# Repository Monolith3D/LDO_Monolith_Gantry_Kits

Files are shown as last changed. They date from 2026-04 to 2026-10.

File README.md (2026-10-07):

[][cc-by-nc-sa]

# LDO Monolith Gantry Kits

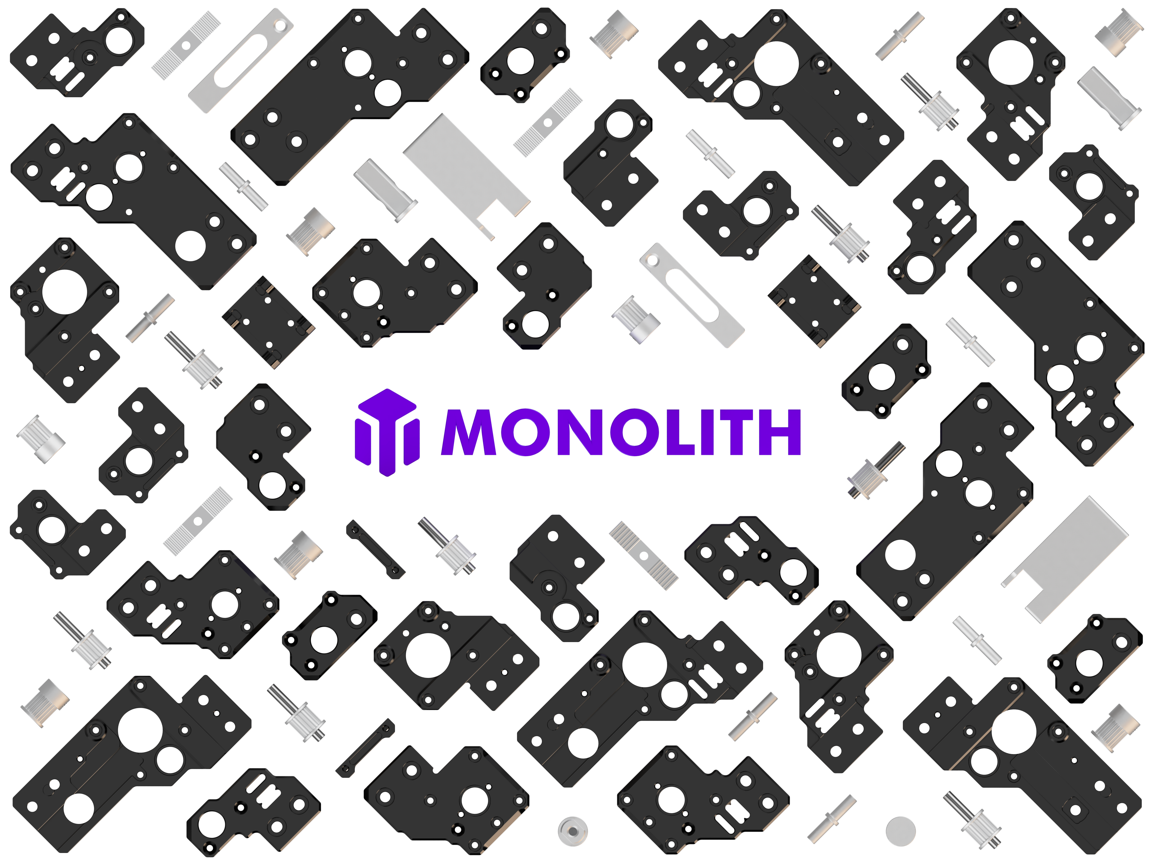
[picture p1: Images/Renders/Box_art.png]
LDO Monolith Gantry Kit box art


Official milled [Monolith Gantry](https://github.com/Monolith3D/Monolith_Gantry) kits and milled Z-joint kits, manufactured by [LDO](https://ldomotion.com/).

## Start Here

<a href="https://build.monolith3d.xyz/">
  <picture>
    <source media="(prefers-color-scheme: dark)" srcset="https://raw.githubusercontent.com/Monolith3D/MISC/main/Common_repo_files/monolith-builder-dark.png">
    <source media="(prefers-color-scheme: light)" srcset="https://raw.githubusercontent.com/Monolith3D/MISC/main/Common_repo_files/monolith-builder-light.png">
    Get started in Monolith Builder
  </picture>
</a>

Monolith Builder guides you through assembly step by step with interactive 3D animations. Legacy PDF assembly manuals remain available during the transition.

- [Legacy PDF assembly manuals](Docs/)
- [Printed parts](STLs/)
- [CAD reference files](CAD/)
- [Batch notes](Docs/batch_notes.md)
- [Photos and renders](Images/)

## Products

### Gantry Kits

[Gantry kit details](Gantry_Kits.md): Milled parts and supporting hardware for 2WD or AWD builds.

**Vendors**

- US: [West3D](https://west3d.com/products/monolith-cnc-gantry-by-ldo-systems-v2-4-and-trident-compatible-with-2wd-and-awd), [Fabreeko](https://www.fabreeko.com/products/monolith-gantry-cnc-kit-by-ldo), [KB-3D](https://kb-3d.com/store/motion/8785-9638-ldo-monolith-awd-9mm-cnc-gantry-kit-r1-multiple-types.html)
- Canada: [3D Lab Tech](https://www.3dlabtech.ca/product/ldo-monolith-cnc-gantry-kit/)
- Australia: [Dremc](https://store.dremc.com.au/products/ldo-monolith-cnc-gantry-kit-v2-4-trident?_pos=2&_sid=165a04a36&_ss=r)
- UK: 123-3D ([V2](https://www.123-3d.co.uk/LDO-Monolith-CNC-Gantry-KIT-Voron-2-4-LDO-MLG-V2-i15158.html), [Trident](https://www.123-3d.co.uk/LDO-Monolith-CNC-Gantry-KIT-Voron-Trident-LDO-MLG-VT-i15159.html)), [onetwo3D](https://www.onetwo3d.co.uk/product/ldo-monolith-cnc-gantry-kit/), [JB3D](https://jb3d.uk/product/cnc-monolith-gantry-by-cloakedwayne/)
- Germany: [3DPartner](https://www.partner-3d.de/3d-druck-ersatzteile/)
- France: [MyRigs](https://myrigs3d.com/products/monolith-cnc-gantry-by-ldo-systems-v2-4-and-trident-compatible-with-2wd-and-awd)
- Hungary: Zen3D Laboratories ([V2](https://shop.zen3d.eu/cnc-monolith-gantry), [Trident](https://shop.zen3d.eu/cnc-monolith-gantry-trident))
- Russia: RRF3D ([V2](https://rrf3dshop.ru/catalog/mekhanika/nabory/nabor-monolith-cnc-gantry-dlya-voron-2-4r2/), [Trident](https://rrf3dshop.ru/catalog/mekhanika/nabory/nabor-monolith-cnc-gantry-4awd-dlya-voron-trident/))
- India: [DConqueror3D](https://dc3d.in/shop/voron-v2-4-parts/ldo-monolith-cnc-gantry-kit/), [Zee3D](https://www.zee3d.in/product-page/monolith-cnc-gantry-kit)
- Sweden: [3D Katten](https://3dkatten.se/products/monolith-cnc-kit-2wd-awd)
- Denmark: 3DO ([V2](https://3do.dk/en/frame-kits/4621-ldo-monolith-cnc-gantry-kit-voron-24-v2.html), [Trident](https://3do.dk/en/frame-kits/4622-ldo-monolith-cnc-gantry-kit-voron-trident-vt.html))
- Norway: [Frem3D](https://frem3d.no/en/products/monolith-cnc-gantry-av-ldo-systems-v2-4-og-trident-med-2wd-og-awd)
- Netherlands: [Levendigs](https://levendigs.com/)
- China: [LDO direct](https://store.ldomotion.com/products/ldo-monolith-cnc-gantry-kit-for-voron-2-4-trident)

### Milled Z-Joint Kit

[Milled Z-joint kit details](Milled_Z_Joints.md): Metal replacements for the hybrid Z-joints in the LDO Monolith V2 Gantry Kit, sold separately.

**Vendors**

- US: [West3D](https://west3d.com/products/monolith-cnc-z-joint-kit-by-ldo-motors)
- France: [MyRigs](https://myrigs3d.com/products/ldo-monolith-cnc-z-joint-kit)
- Hungary: [Zen3D Laboratories](https://shop.zen3d.eu/monolith-cnc-z-joint-kit)

## Support

For kit hardware defects or missing kit hardware, use the LDO or reseller support path.

For Monolith design, configuration, and documentation questions, use the Monolith documentation and community channels.

For third-party toolheads, probes, electronics, or firmware behavior, check the relevant upstream project.

Join the Discord (https://discord.gg/sJQeTYUPuy)
Join the Monolith Discord (https://discord.gg/monolith3d)

[Design, production, and testing acknowledgements](Acknowledgements.md)

<br/><br/><br/><br/>
This work is licensed under a
[Creative Commons Attribution-NonCommercial-ShareAlike 4.0 International License][cc-by-nc-sa].

[][cc-by-nc-sa]

[cc-by-nc-sa]: http://creativecommons.org/licenses/by-nc-sa/4.0/
[cc-by-nc-sa-image]: https://licensebuttons.net/l/by-nc-sa/4.0/88x31.png
[cc-by-nc-sa-shield]: https://img.shields.io/badge/License-CC%20BY--NC--SA%204.0-lightgrey.svg

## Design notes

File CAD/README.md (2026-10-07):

# CAD

This folder contains STEP reference files for kit-specific subassemblies, printed parts, and helper tools.

For a complete gantry assembly as a single STEP file, select your configuration and printer size in [Monolith Builder](https://build.monolith3d.xyz/). The generated assembly is included in the downloadable build package.

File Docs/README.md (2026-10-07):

## Monolith Builder

<a href="https://build.monolith3d.xyz/">
  <picture>
    <source media="(prefers-color-scheme: dark)" srcset="https://raw.githubusercontent.com/Monolith3D/MISC/main/Common_repo_files/monolith-builder-dark.png">
    <source media="(prefers-color-scheme: light)" srcset="https://raw.githubusercontent.com/Monolith3D/MISC/main/Common_repo_files/monolith-builder-light.png">
    Get started in Monolith Builder
  </picture>
</a>

Monolith Builder guides you through assembly step by step with interactive 3D animations. Legacy PDF assembly manuals remain available during the transition.

## Legacy PDF Assembly Manuals

| Printer | Batch 1 | Batch 2+ |
|---|---|---|
| Voron V2 | [V2 Batch 1](LDO_Monolith_Gantry_Kit_Manual_V2_Batch_1.pdf) | [V2 Batch 2+](LDO_Monolith_Gantry_Kit_Manual_V2_Batch_2_Plus.pdf) |
| Voron Trident | [Trident Batch 1](LDO_Monolith_Gantry_Kit_Manual_VT_Batch_1.pdf) | [Trident Batch 2+](LDO_Monolith_Gantry_Kit_Manual_VT_Batch_2_Plus.pdf) |

## Batch Notes

Check the [batch notes](batch_notes.md) before assembly.

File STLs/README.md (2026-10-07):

# STLs

This folder contains the LDO-kit-specific printed parts and helper tools.

## Included Here

- [LDO_V2_FT_spacer.stl](LDO_V2_FT_spacer.stl)
- [LDO_9mm_VT_NP_spacer.stl](LDO_9mm_VT_NP_spacer.stl)
- [LDO_9mm_pulley_alignment_helper.stl](Tools/LDO_9mm_pulley_alignment_helper.stl)
- [Cable_management_clip_L.stl](Cable_management/Cable_management_clip_L.stl)
- [Cable_management_clip_M.stl](Cable_management/Cable_management_clip_M.stl)
- [Cable_management_clip_S.stl](Cable_management/Cable_management_clip_S.stl)

## Shared with Main Monolith Gantry

Some printed files used by this kit are shared with the main Monolith Gantry repo:

- [Hybrid_V2_Z_joint_a.stl](https://github.com/Monolith3D/Monolith_Gantry/blob/main/STLs/Z_joints/Hybrid_Z_joints/Hybrid_V2_Z_joint_a.stl)
- [Hybrid_V2_Z_joint_b.stl](https://github.com/Monolith3D/Monolith_Gantry/blob/main/STLs/Z_joints/Hybrid_Z_joints/Hybrid_V2_Z_joint_b.stl)
- [Printed_Hybrid_V2_Z_joint_spacer_NP.stl](https://github.com/Monolith3D/Monolith_Gantry/blob/main/STLs/Z_joints/Printed_Hybrid_V2_Z_joint_spacer_NP.stl)
- [V2_Z_idler_spacer.stl](https://github.com/Monolith3D/Monolith_Gantry/blob/main/STLs/V2_Z_idler_spacer.stl)
- [X_endstop_housing.stl](https://github.com/Monolith3D/Monolith_Gantry/blob/main/STLs/X_endstop_housing.stl)
- [Y_endstop_housing.stl](https://github.com/Monolith3D/Monolith_Gantry/blob/main/STLs/Y_endstop_housing.stl)

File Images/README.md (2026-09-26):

# Images

## Renders

| Image | Image | Image |
| --- | --- | --- |
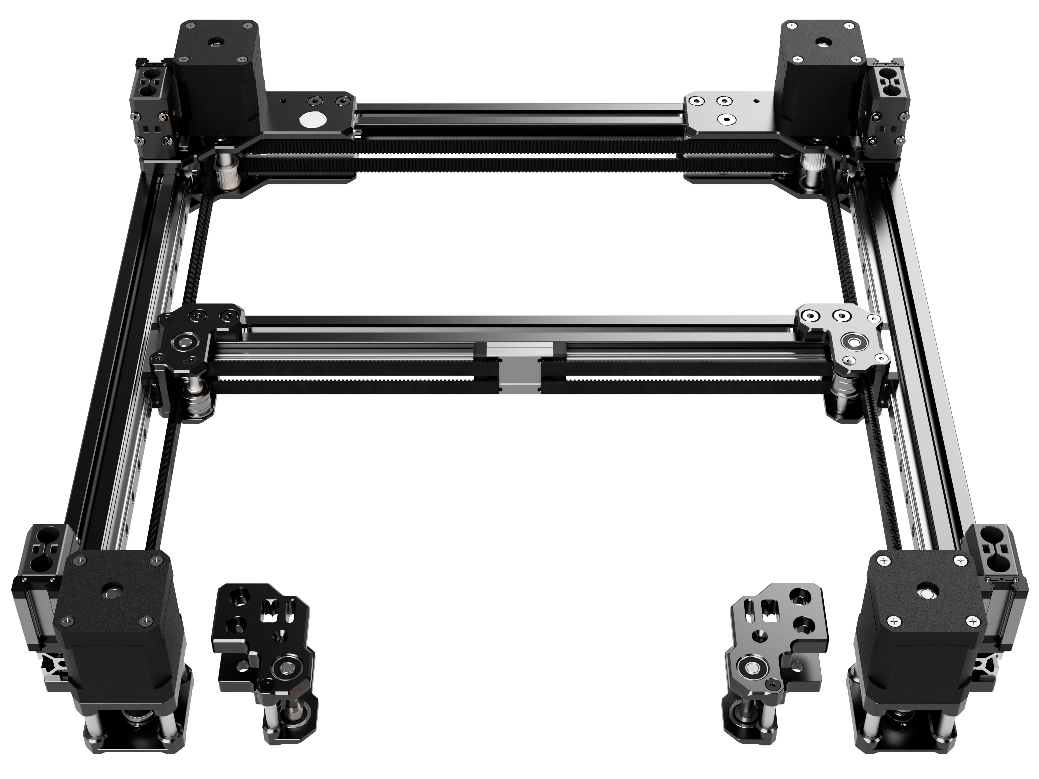
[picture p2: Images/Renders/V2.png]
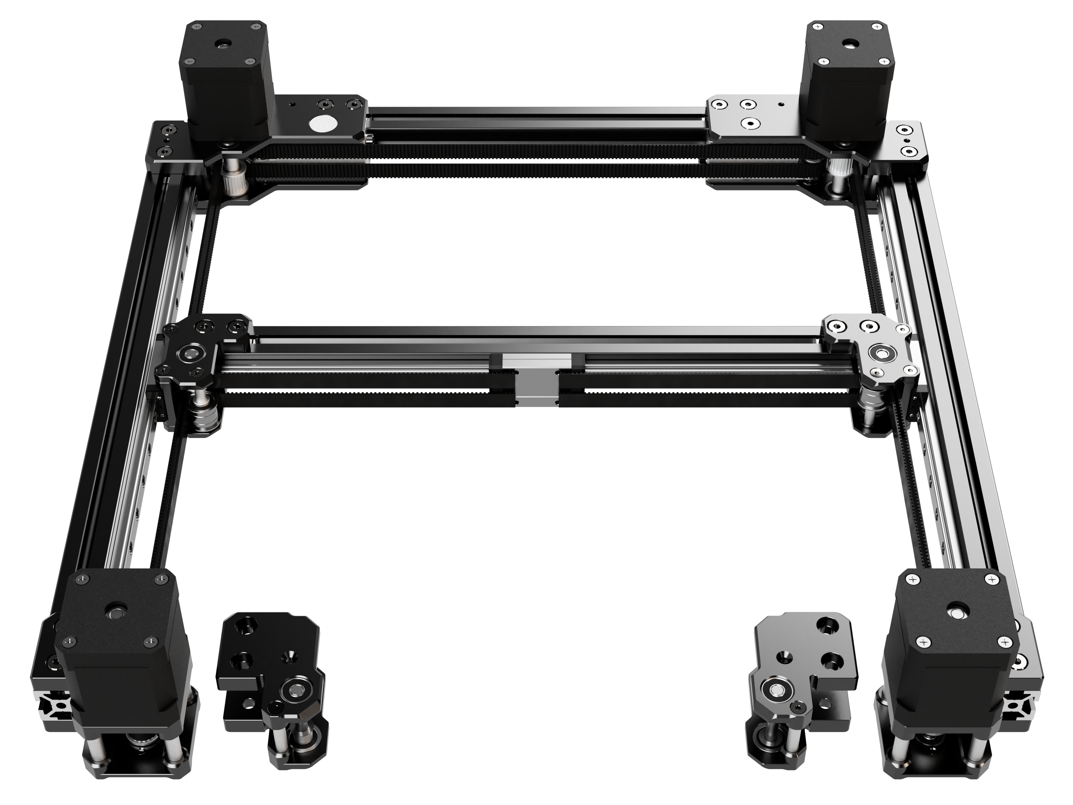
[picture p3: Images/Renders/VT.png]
| [<br>Box art](Renders/Box_art.png) | [<br>V2 kit render](Renders/V2.png) | [<br>VT kit render](Renders/VT.png) |
| [<br>XY-joint](Renders/XY-joint.png) | [<br>Rear mount](Renders/Rear_mount.png) | [<br>Front mount](Renders/Front_mount.png) |

## Milled Z-joint kit

| Image | Image | Image |
| --- | --- | --- |
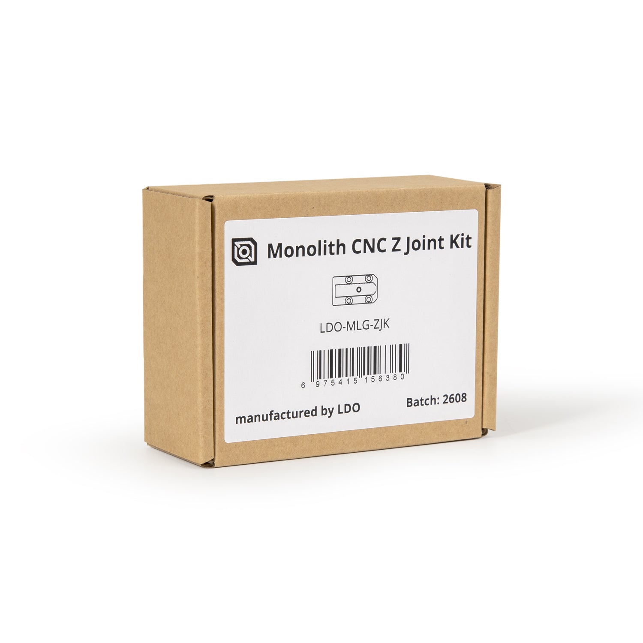
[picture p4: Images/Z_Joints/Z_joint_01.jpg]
Packaging
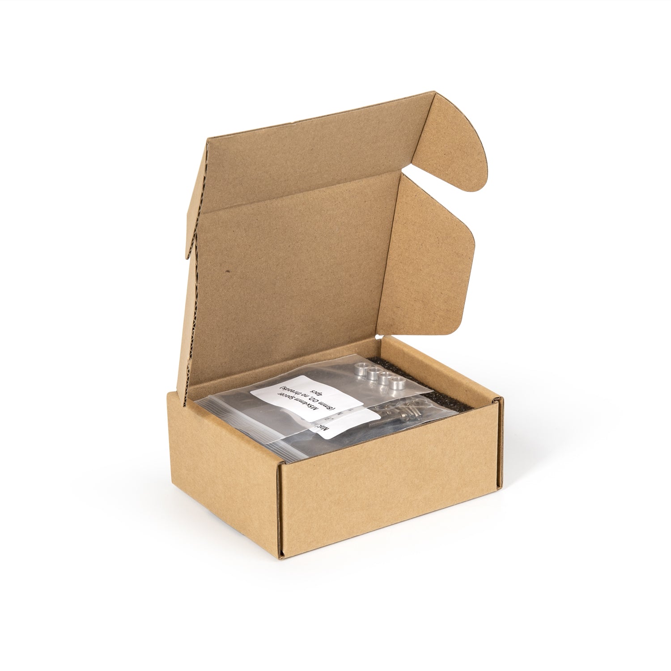
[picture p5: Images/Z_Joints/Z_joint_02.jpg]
Open box
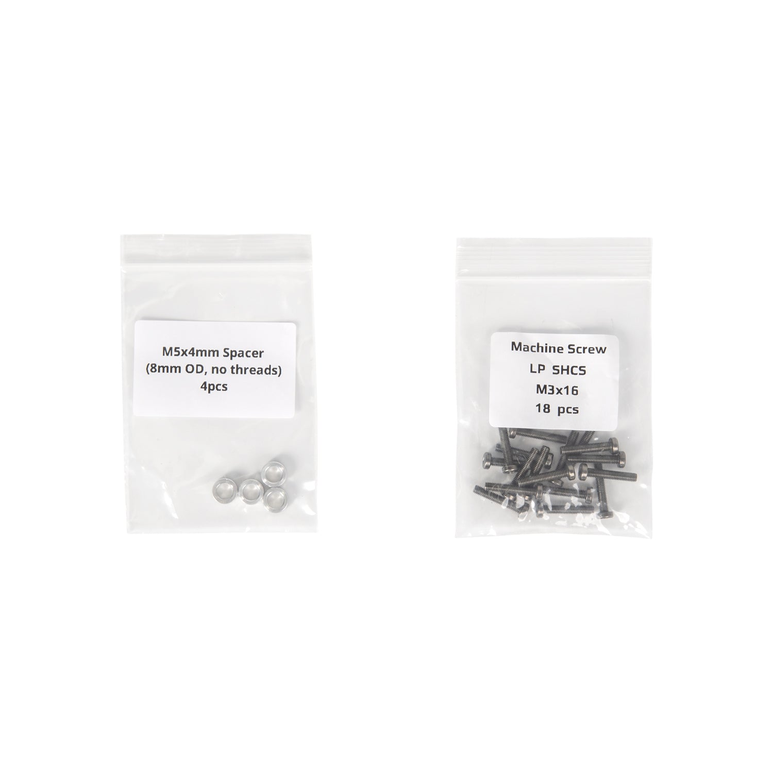
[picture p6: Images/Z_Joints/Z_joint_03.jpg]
Fasteners and spacers
| [<br>Packaging](Z_Joints/Z_joint_01.jpg) | [<br>Open box](Z_Joints/Z_joint_02.jpg) | [<br>Fasteners and spacers](Z_Joints/Z_joint_03.jpg) |
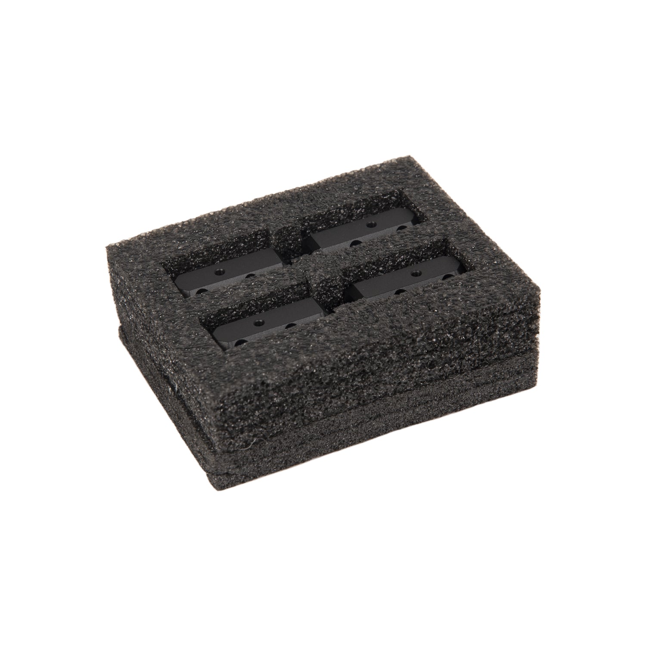
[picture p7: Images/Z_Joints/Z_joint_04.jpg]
Packed joints
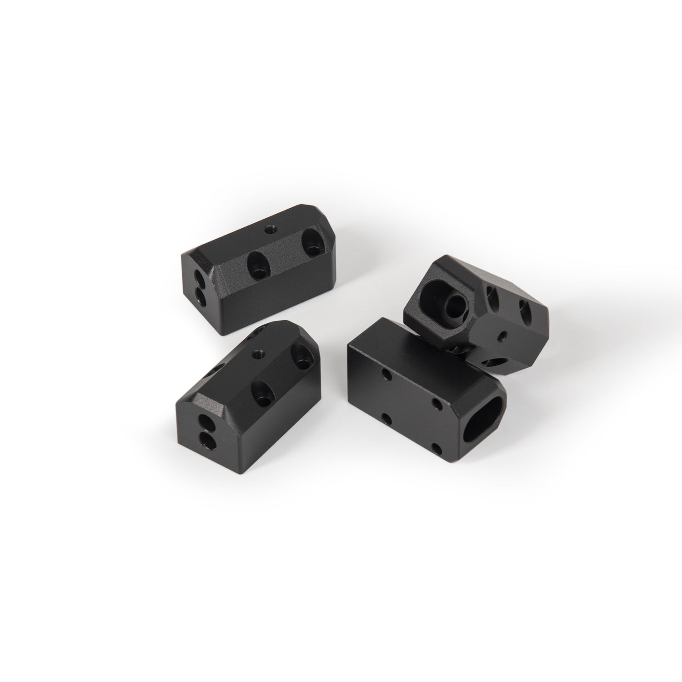
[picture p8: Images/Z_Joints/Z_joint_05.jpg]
Joint set
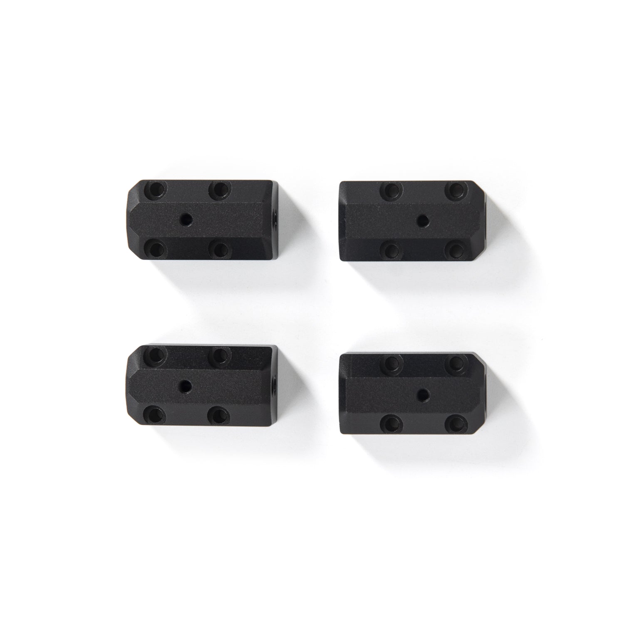
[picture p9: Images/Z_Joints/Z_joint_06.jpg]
Joint set, front view
| [<br>Packed joints](Z_Joints/Z_joint_04.jpg) | [<br>Joint set](Z_Joints/Z_joint_05.jpg) | [<br>Joint set, front view](Z_Joints/Z_joint_06.jpg) |
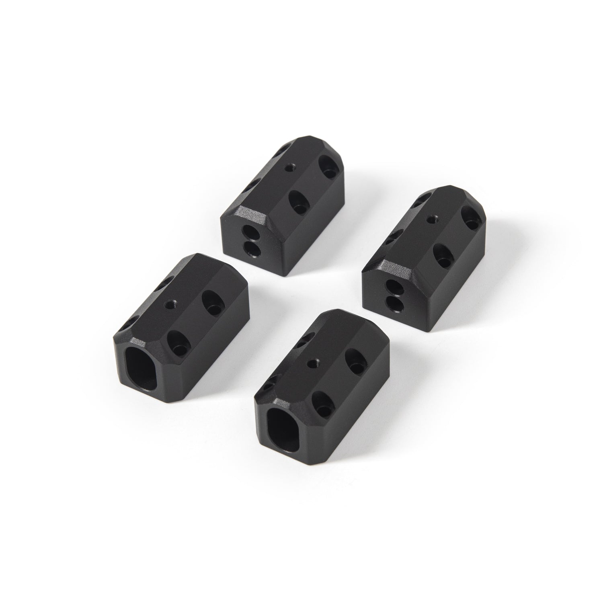
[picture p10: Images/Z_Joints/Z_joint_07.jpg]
Joint set, angled view
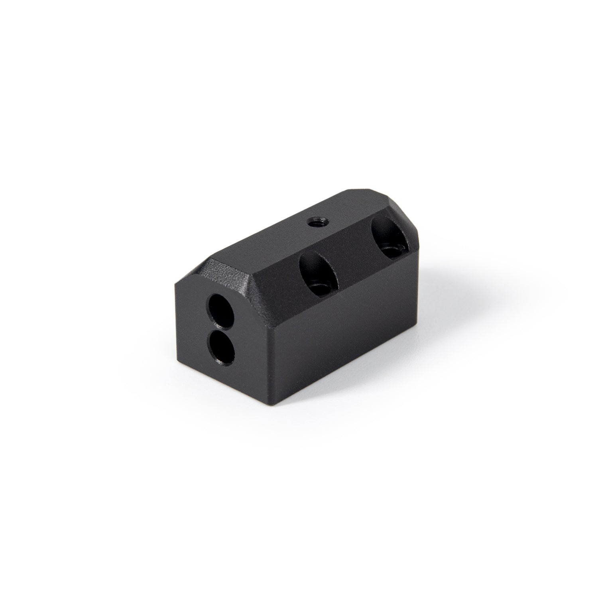
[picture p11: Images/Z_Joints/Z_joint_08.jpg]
Joint detail 1
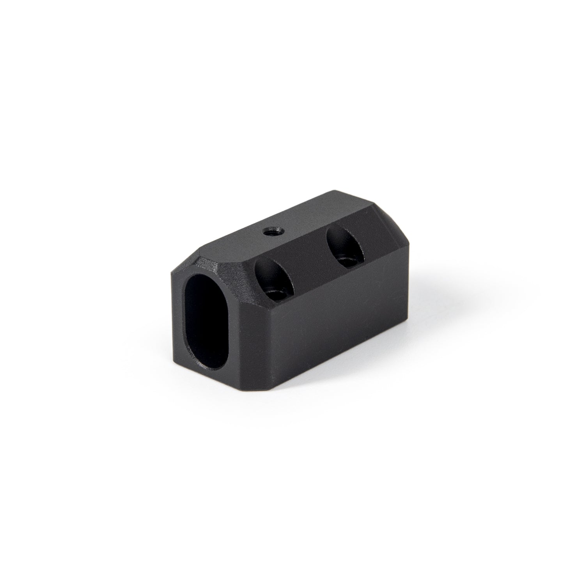
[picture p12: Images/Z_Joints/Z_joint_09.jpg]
Joint detail 2
| [<br>Joint set, angled view](Z_Joints/Z_joint_07.jpg) | [<br>Joint detail 1](Z_Joints/Z_joint_08.jpg) | [<br>Joint detail 2](Z_Joints/Z_joint_09.jpg) |
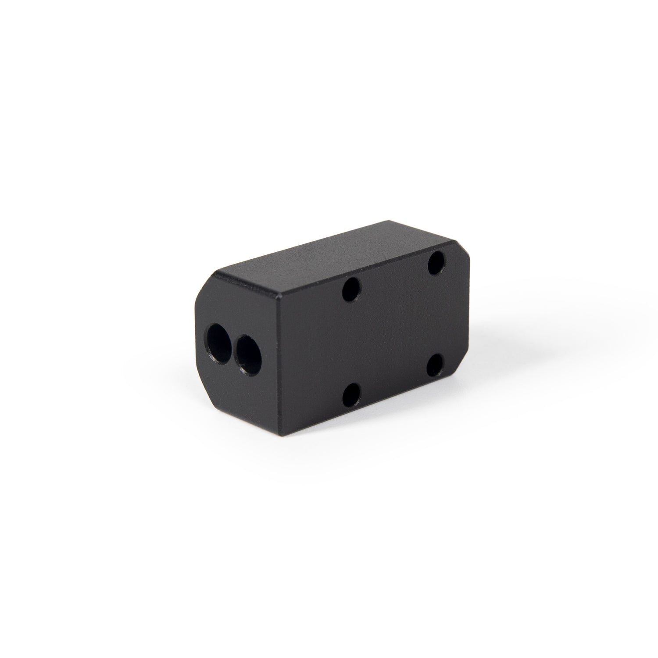
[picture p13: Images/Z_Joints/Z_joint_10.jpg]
Joint detail 3
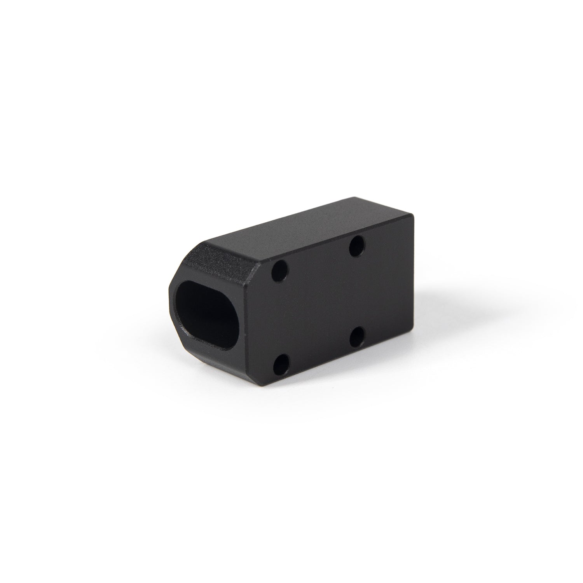
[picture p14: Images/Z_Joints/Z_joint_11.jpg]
Joint detail 4
| [<br>Joint detail 3](Z_Joints/Z_joint_10.jpg) | [<br>Joint detail 4](Z_Joints/Z_joint_11.jpg) |  |

## V2 gantry kit

### Kit Photos

| Image | Image | Image |
| --- | --- | --- |
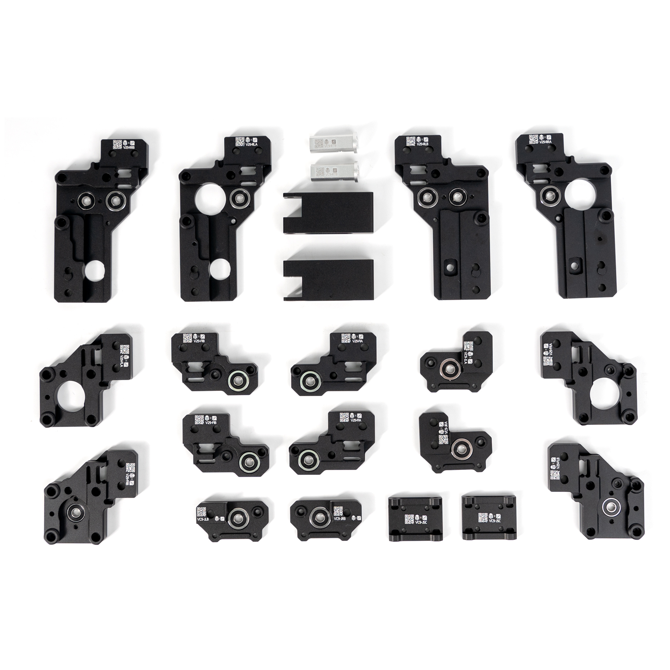
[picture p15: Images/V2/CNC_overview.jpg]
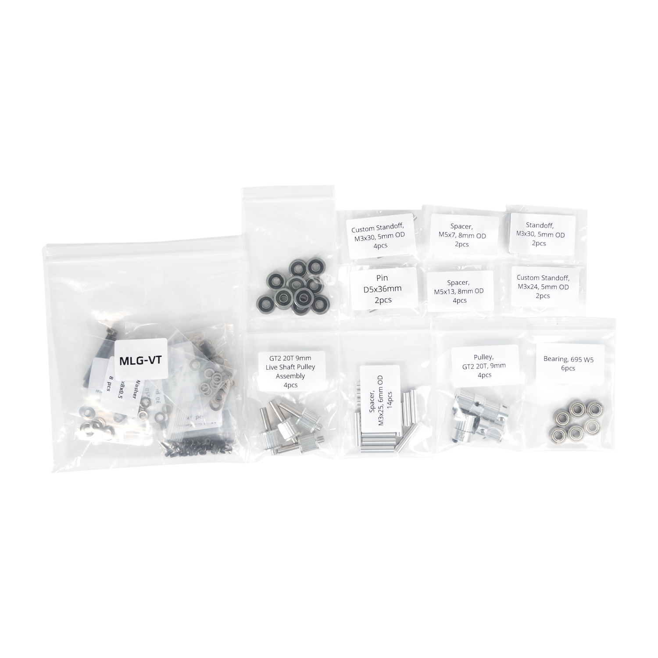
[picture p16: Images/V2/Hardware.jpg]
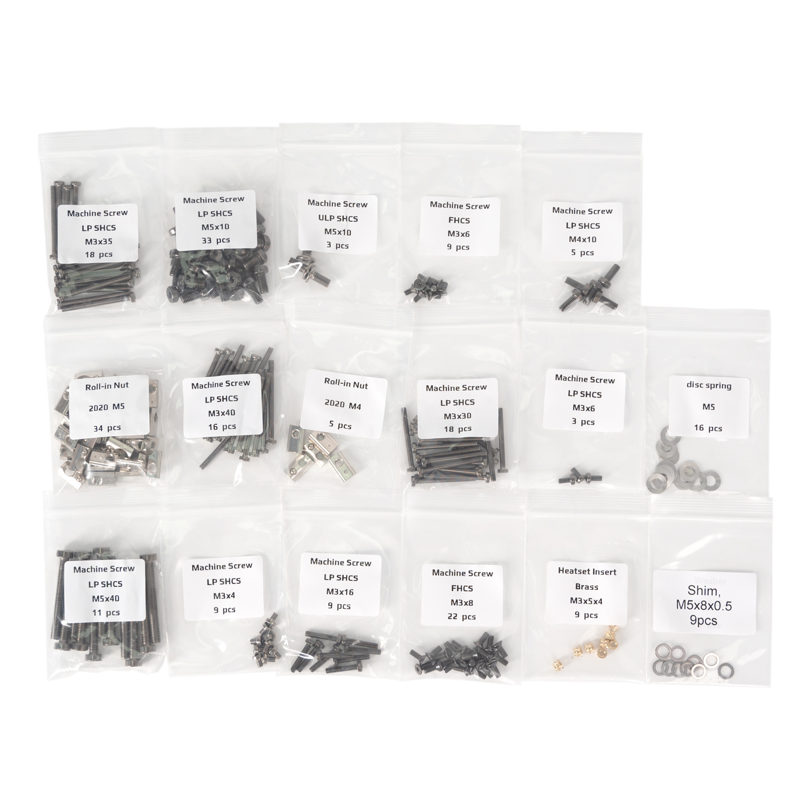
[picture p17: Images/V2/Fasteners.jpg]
| [<br>CNC overview](V2/CNC_overview.jpg) | [<br>Hardware](V2/Hardware.jpg) | [<br>Fasteners](V2/Fasteners.jpg) |
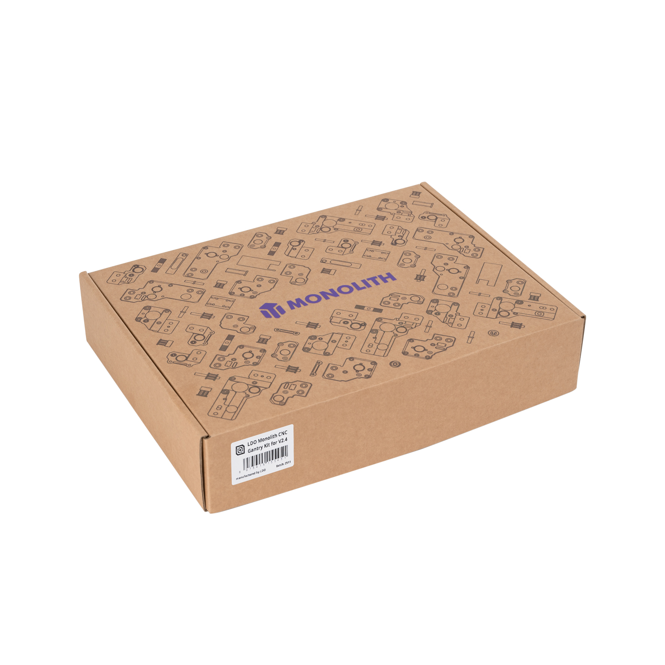
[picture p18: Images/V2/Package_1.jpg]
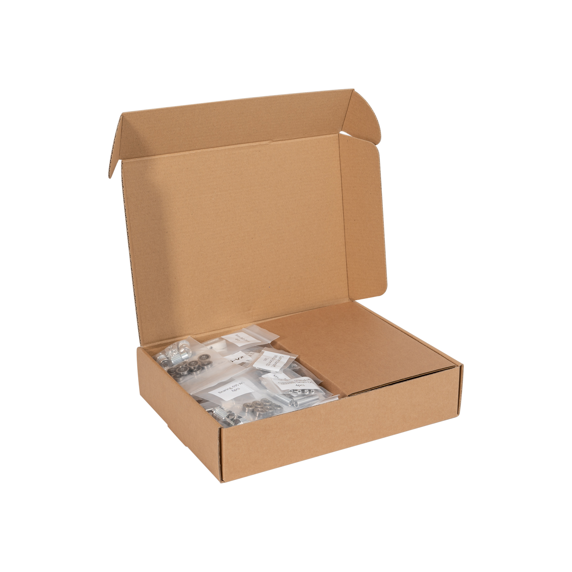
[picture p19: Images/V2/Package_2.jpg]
| [<br>Package 1](V2/Package_1.jpg) | [<br>Package 2](V2/Package_2.jpg) |  |

### Part Reference Photos

| Image | Image | Image |
| --- | --- | --- |
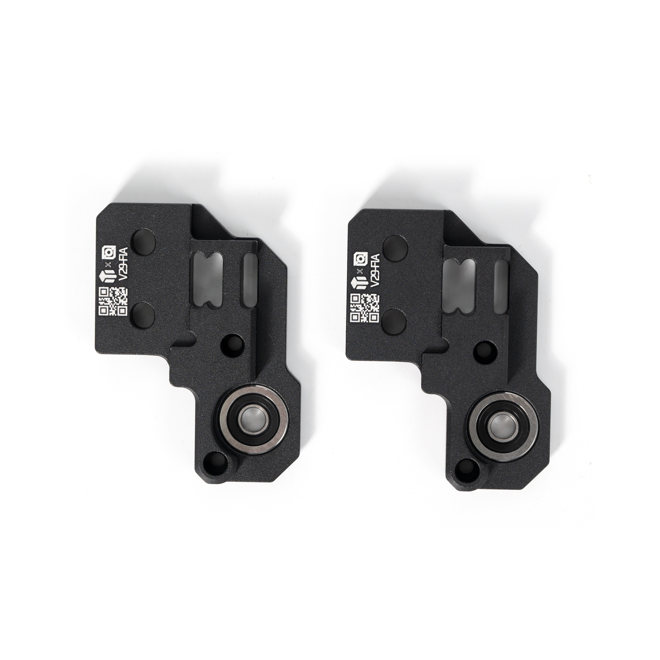
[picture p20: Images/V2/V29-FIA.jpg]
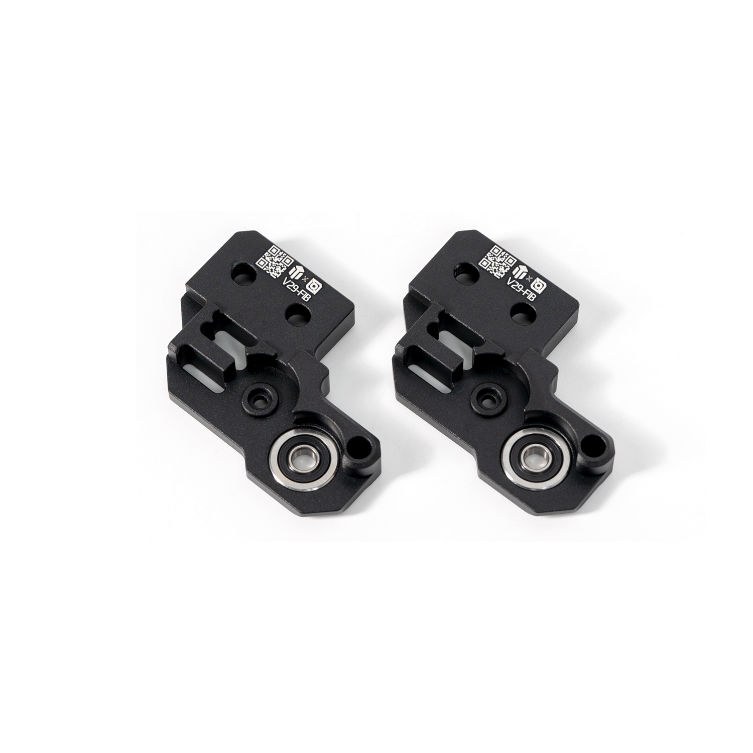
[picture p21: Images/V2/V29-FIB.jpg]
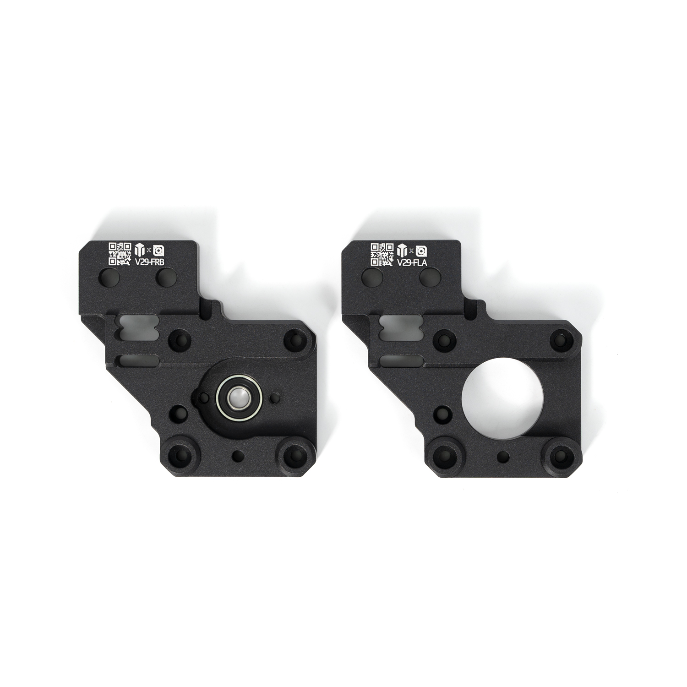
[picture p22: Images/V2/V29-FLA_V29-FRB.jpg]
| [<br>V29-FIA](V2/V29-FIA.jpg) | [<br>V29-FIB](V2/V29-FIB.jpg) | [<br>V29-FLA / V29-FRB](V2/V29-FLA_V29-FRB.jpg) |
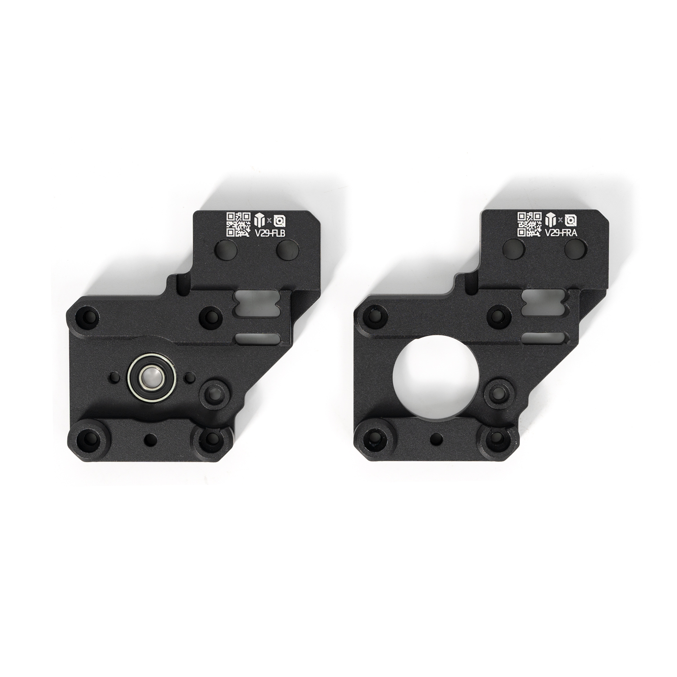
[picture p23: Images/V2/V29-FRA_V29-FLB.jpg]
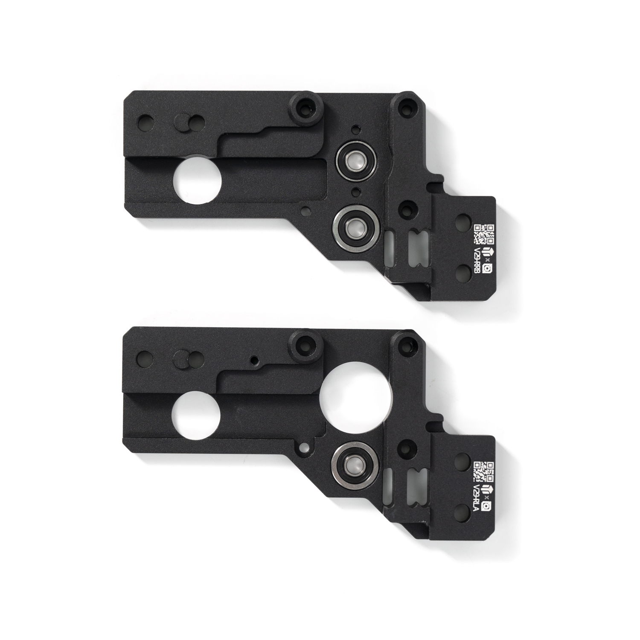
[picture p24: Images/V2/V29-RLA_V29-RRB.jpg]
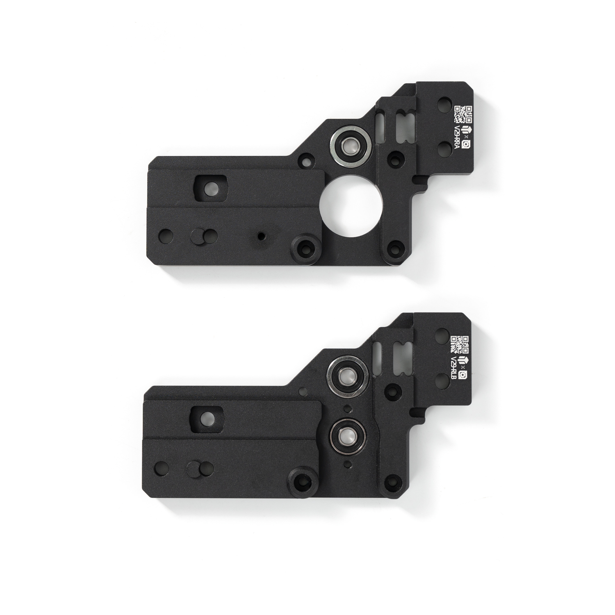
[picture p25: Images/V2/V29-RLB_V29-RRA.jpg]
| [<br>V29-FRA / V29-FLB](V2/V29-FRA_V29-FLB.jpg) | [<br>V29-RLA / V29-RRB](V2/V29-RLA_V29-RRB.jpg) | [<br>V29-RLB / V29-RRA](V2/V29-RLB_V29-RRA.jpg) |
| [<br>VC9-JLA / VC9-JRA](V2/VC9-JLA_VC9-JRA.jpg) | [<br>VC9-JLB / VC9-JRB](V2/VC9-JLB_VC9-JRB.jpg) | [<br>VC9-JSC](V2/VC9-JSC.jpg) |
| [<br>VC9-RTA](V2/VC9-RTA.jpg) | [<br>VC9-RTB](V2/VC9-RTB.jpg) |  |

## Trident gantry kit

### Kit Photos

| Image | Image | Image |
| --- | --- | --- |
| [<br>CNC overview](VT/CNC_overview.jpg) | [<br>Hardware](VT/Hardware.jpg) | [<br>Fasteners](VT/Fasteners.jpg) |
| [<br>Package 1](VT/Package_1.jpg) | [<br>Package 2](VT/Package_2.jpg) |  |

### Part Reference Photos

| Image | Image | Image |
| --- | --- | --- |
| [<br>VT9-FIA](VT/VT9-FIA.jpg) | [<br>VT9-FIB](VT/VT9-FIB.jpg) | [<br>VT9-FLA / VT9-FRB](VT/VT9-FLA_VT9-FRB.jpg) |
| [<br>VT9-FRA / VT9-FLB](VT/VT9-FRA_VT9-FLB.jpg) | [<br>VT9-RLA / VT9-RRB](VT/VT9-RLA_VT9-RRB.jpg) | [<br>VT9-RLB / VT9-RRA](VT/VT9-RLB_VT9-RRA.jpg) |
| [<br>VC9-JLA / VC9-JRA](VT/VC9-JLA_VC9-JRA.jpg) | [<br>VC9-JLB / VC9-JRB](VT/VC9-JLB_VC9-JRB.jpg) | [<br>VC9-JSC](VT/VC9-JSC.jpg) |
| [<br>VC9-RTA](VT/VC9-RTA.jpg) | [<br>VC9-RTB](VT/VC9-RTB.jpg) |  |

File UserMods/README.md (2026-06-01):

# User Mods

This folder is for community-made additions, adaptations, and compatibility parts for the LDO Monolith Gantry kits.

User mods are not official LDO kit files unless stated otherwise. Check the mod author, target printer, kit variant, drive layout, fit layout, and toolhead assumptions before printing or ordering parts.

Use the folder structure `username/usermod_name` for new user mods.

Good user mod folders should include:

- A short `README.md` explaining what the mod does
- Clear compatibility notes for V2 or VT, 2WD or AWD, and NP or FT where relevant
- STL, CAD, image, and BOM files needed to understand the mod
- Assembly notes or warnings if the mod changes belt path, endstops, travel, docks, panels, or toolhead clearance
- Credit and license notes when the mod reuses work from another project

Use user mods at your own risk. They may not receive updates when the main kit, manuals, or Monolith Gantry files change.

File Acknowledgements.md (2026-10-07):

# Acknowledgements

[Repository overview](README.md)

**Designer**  
CloakedWayne

**Project Coordinator**  
JasonFromLDO

**Design Consultant**  
DaveFromLDO  
Scarecrow  
The_Adeo

**Production**  
LDO Motors

**Testing**  
Brazuka  
The_Adeo  
Scarecrow  
Zakfarias  
SyNoon  
JoseFromLDO us  
Kittie Katt  
Reth  
JaredC01  
Tae  
TheVoronModder

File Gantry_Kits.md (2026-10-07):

# LDO Monolith Gantry Kits

[Repository overview](README.md)

Official milled [Monolith Gantry](https://github.com/Monolith3D/Monolith_Gantry) kits for Voron V2 and Voron Trident, manufactured by [LDO](https://ldomotion.com/).

Milled parts and supporting hardware for 2WD or AWD builds.

## What is Included

The kit includes the milled gantry parts and supporting hardware for the selected printer variant.

Key kit features:

- CNC/milled Monolith Gantry parts
- Parts for both 2WD and AWD configurations
- Robust removable tensioners for belting and pre-tensioning
- 9/10 mm belt support, depending on toolhead compatibility
- Genuine Gates pulleys and press-fit live-shaft idlers
- AWD front extrusion support for tool changer setups

The kit does not include belts, steppers, toolhead, probe, electronics, printer-specific frame or panel upgrades, or firmware mods.

## Printed Parts and Shared Files

Kit-specific prints, helper tools, and shared Monolith Gantry STL links are listed in [STLs](STLs).

The user manuals show where these printed parts and helper tools are used during assembly.

## Choosing 2WD or AWD

These kits are intended for standard 250-350 mm bed sizes.

2WD is the safer starting point for stock or lightly modified machines, especially with printed or modular toolheads, stock panels, or a frame that has not been stiffened.

AWD is most useful when the rest of the printer is ready to benefit from the added belt stiffness. That means the frame, panels, toolhead, and X-rail all need to support the higher-stiffness path.

> [!NOTE]
> AWD is not automatically better for every printer. On a less rigid machine, 2WD is probably the better configuration.

The user manuals show the configuration-specific 2WD and AWD assembly paths.

## Steppers

LDO 2504 Speedy Power steppers are the known-good baseline for this kit. LDO 2504 S45R "Monolith Edition" steppers are commonly bundled with the kits, and their shaft length is compatible across the Monolith Gantry platform.

Alternate NEMA17 steppers may work, but the stepper shafts need to be 5 mm in diameter and at least 37 mm long to work with the kit in double-shear. 8 mm shaft diameter can work, but only in single-shear.

Some Batch 1 kits may have documented stepper screw engagement problems. Check the [batch notes](#batch-notes) before installing motors.

## NP and FT

NP means No Protrusion. It keeps the gantry inside the stock frame or panel footprint by moving the relevant mounts and belt path inward.

FT means Full Travel. It prioritizes travel, but it may require clearance changes around panels, doors, or vertical extrusions.

Physical fit and performance recommendation are separate questions. A layout can fit inside the printer and still be the wrong performance path if the rest of the machine cannot use the added stiffness.

The user manuals include the detailed NP and FT layout explanation, clearance notes, and spacer placement.

## Toolhead Compatibility

See [Toolheads for Monolith](https://github.com/Monolith3D/Toolheads_for_Monolith) for compatible toolheads, belt clamps, and guidance on stiffness, clearance, and endstops.

## Rail Notes

The LDO milled XY-joints use MGN9H Y-carriages. Z0 / no preload is recommended for the Y-rails to avoid extra wear or binding. Other preload classes can work.

For the separate X-rail recommendation, see the [toolhead design guidelines](https://github.com/Monolith3D/Toolheads_for_Monolith/tree/main/Design_Guidelines#stiffness-and-center-of-mass).

## Batch Notes

Check the [batch notes](Docs/batch_notes.md) before assembly.

## Vendors

See the [gantry kit vendors](README.md#gantry-kits).

## Photos and Renders

- [V2 gantry kit photos](Images/README.md#v2-gantry-kit)
- [Trident gantry kit photos](Images/README.md#trident-gantry-kit)
- [Kit and part renders](Images/README.md#renders)

LDO Monolith Gantry Kit VT render

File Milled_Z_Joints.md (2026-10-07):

# LDO Monolith Milled Z-Joint Kit

[Repository overview](README.md)

CNC-milled metal replacements for the hybrid Z-joints supplied with the LDO Monolith V2 Gantry Kit. **This Z-joint kit is sold separately from the main gantry kit.**

## Compatibility

- **Only compatible with the LDO Monolith V2 Gantry Kit.**
- **Not compatible with printed or sheet-metal Monolith gantries.**

## Features

- **Heat resistance:** Metal construction provides greater heat resistance than hybrid joints.
- **Controlled rotational compliance:** Included spacers create a smaller clamping surface, designed to reduce the risk of binding compared to other rigid metal Z-joints.
- **Matching finish:** Bead-blasted and black-anodized to match the LDO gantry.
- **Cable management:** M3 threaded mounting hole for cable clips.
- **Double-Z support:** Use two kits with two compatible carriages on each Z rail.

## Installation

Select the milled Z-joint option in [Monolith Builder](https://build.monolith3d.xyz/) for step-by-step installation guidance. These joints are not yet covered in the PDF manuals.

## Kit Contents

- 4 milled Z-joints
- 4 spacers
- M3 mounting screws

**M5 screws are reused from the gantry kit.**

## Vendors

See the [milled Z-joint kit vendors](README.md#milled-z-joint-kit).

[Milled Z-joint kit photos](Images/README.md#milled-z-joint-kit)

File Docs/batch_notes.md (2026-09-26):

# Batch Notes

Read these before assembly. If a note is not listed for your batch, do not assume an older issue still applies.

## Batch 2

- Stepper screw engagement: fixed with flat head screws.
- Live-shaft bearings: come pre-installed with Loctite 641 medium strength retaining compound, a grade made for serviceable fits, as an interface between the anodized aluminum parts and the bearings, with the axial preload unchanged from Batch 1.

No user action is needed.

## Batch 1

- Flanged-bearing hole depth: corrected at the factory with shims glued in under the bearings. No builder action, and any separately packaged shims are spares.
- Stepper screw engagement: use M3 spring washers, or any other small-OD M3 washers, in the stepper mounting counterbores. This affects steppers with shallower threaded holes than the common 48 mm body LDO motors.

Glued-in shims under the flanged bearings

### LDO Announcement: Flanged-Bearing Hole Depth Issue

JasonFromLDO, March 12, 2026

#### Update on the Monolith CNC Gantry Kits

Dear valued customers and partners,

During the conversion to internal production files, the depth of certain component holes was incorrectly specified. A mistake that wasn't present in the original package we received from the designer. Unfortunately, it was only discovered after the production was completed. LDO takes full responsibility for this issue and the delay.

We know many of you have been eagerly awaiting this release, and we sincerely apologize for the delay. A solution has already been implemented for the manufacturing issue. Everything is now on track, and we are working diligently to ensure you receive your kits as soon as possible.

Estimated shipping time from China will be the end of March or early April, and arrival at resellers around the end of April. Thank you for your patience and continued support. Most our resellers will start to take pre-order after we make the shipment.

Thank you for your attention for this matter.

LDO Team  
March 12, 2026

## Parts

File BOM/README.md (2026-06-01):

# BOM

The CSV files under this folder list parts that are not included in the LDO kits themselves.

Use them as supplemental BOM references for the matching configuration, not as complete kit contents lists.

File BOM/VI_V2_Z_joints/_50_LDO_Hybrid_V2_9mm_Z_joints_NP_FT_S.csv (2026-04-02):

Part Name | Quantity
Hybrid_V2_Z_joint_a | 2
Hybrid_V2_Z_joint_b | 2
Printed_Hybrid_V2_Z_joint_spacer_NP | 2
V2_Z_idler_spacer | 2

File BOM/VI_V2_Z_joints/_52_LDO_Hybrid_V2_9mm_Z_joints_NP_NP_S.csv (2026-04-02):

Part Name | Quantity
Hybrid_V2_Z_joint_a | 2
Hybrid_V2_Z_joint_b | 2
Printed_Hybrid_V2_Z_joint_spacer_NP | 4
V2_Z_idler_spacer | 4

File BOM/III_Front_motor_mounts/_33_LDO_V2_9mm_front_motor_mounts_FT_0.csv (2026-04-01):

Part Name | Quantity
NEMA17 with 45mm long shaft | 2
LDO_V2_FT_spacer | 2

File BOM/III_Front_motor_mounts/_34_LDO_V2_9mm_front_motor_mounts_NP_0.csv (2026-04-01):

Part Name | Quantity
NEMA17 with 45mm long shaft | 2

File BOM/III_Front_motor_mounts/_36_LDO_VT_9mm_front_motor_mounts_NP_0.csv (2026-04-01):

Part Name | Quantity
NEMA17 with 45mm long shaft | 2
VT_NP_spacer | 4

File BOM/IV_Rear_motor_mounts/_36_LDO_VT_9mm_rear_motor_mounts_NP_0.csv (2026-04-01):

Part Name | Quantity
NEMA17 with 45mm long shaft | 2
VT_NP_spacer | 4
2020 corner bracket | 1
M5 2020 drop-in T-nut | 4
M5x8 BHCS | 4

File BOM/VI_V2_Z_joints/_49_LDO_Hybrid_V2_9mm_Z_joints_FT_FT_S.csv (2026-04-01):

Part Name | Quantity
Hybrid_V2_Z_joint_a | 2
Hybrid_V2_Z_joint_b | 2

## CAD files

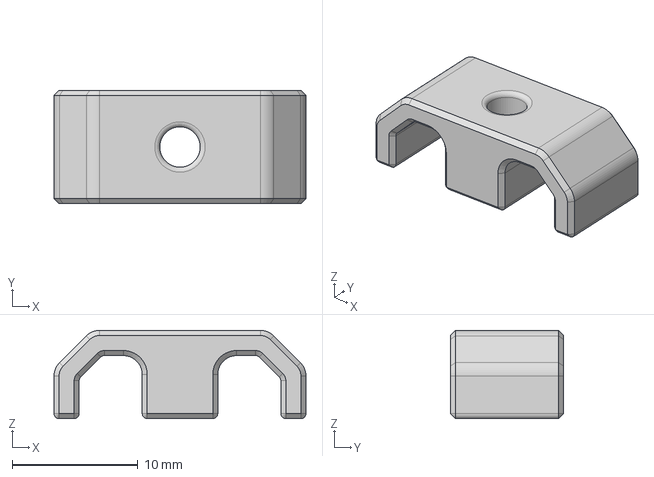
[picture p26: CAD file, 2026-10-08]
CAD/Cable_management/Cable_management_clip_S.step
20.0 x 9.00 x 7.00 mm

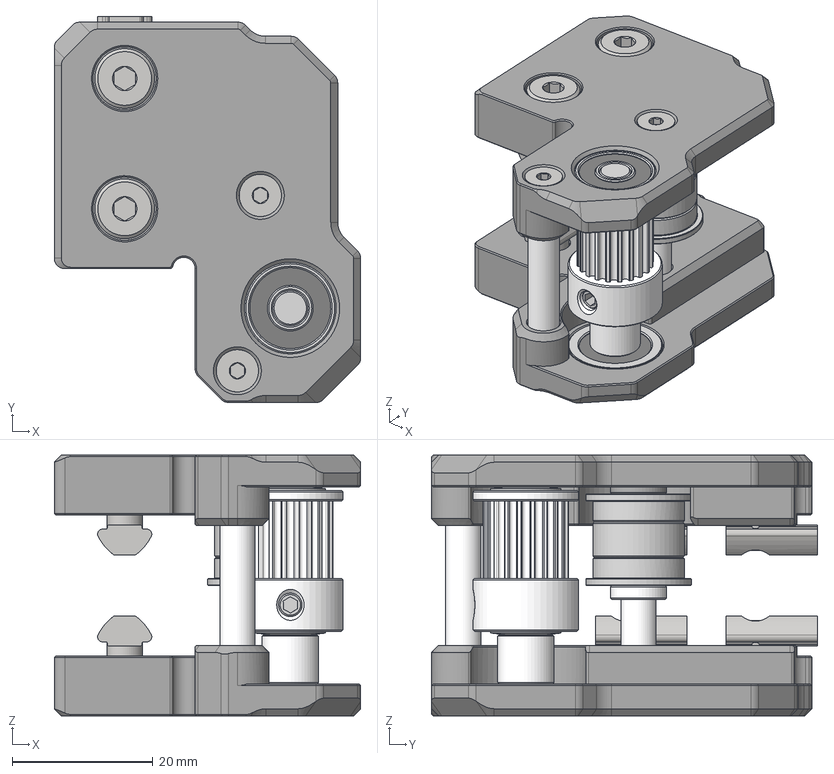
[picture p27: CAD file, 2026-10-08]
CAD/Front_left/LDO_2WD_VT_9mm.step
43.5 x 54.8 x 37.0 mm
GT2 20T toothed core
Pulley flange 15x10x1.5mm
Pulley removable hub 15x10x7.5mm

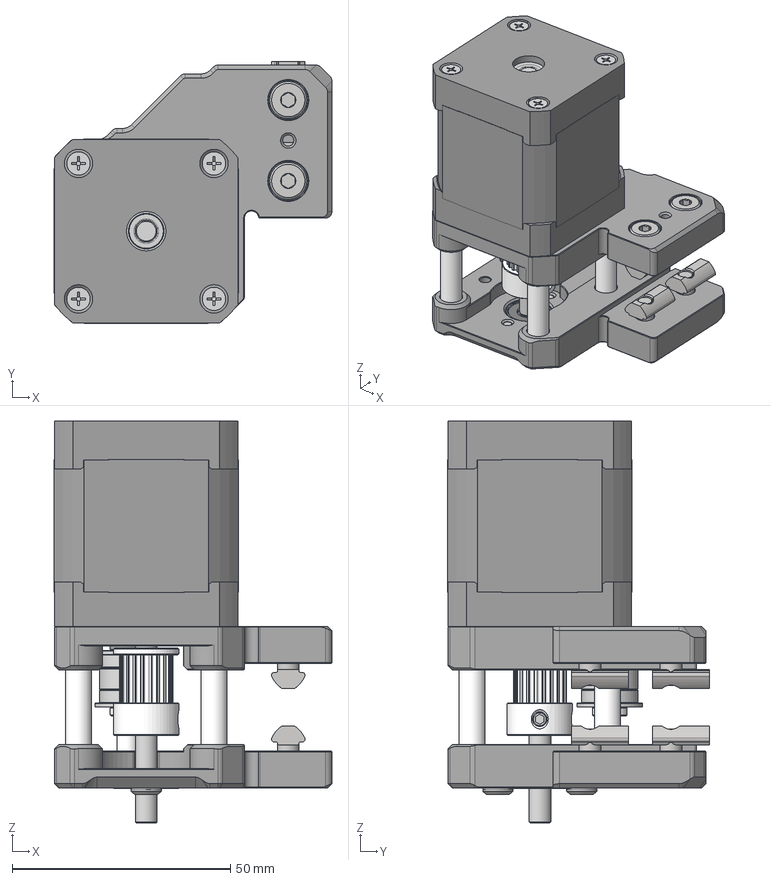
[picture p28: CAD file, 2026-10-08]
CAD/Front_right/LDO_AWD_VT_9mm_0_FT.step
63.6 x 59.9 x 92.0 mm
GT2 20T toothed core
Pulley flange 15x10x1.5mm
Pulley removable hub 15x10x7.5mm

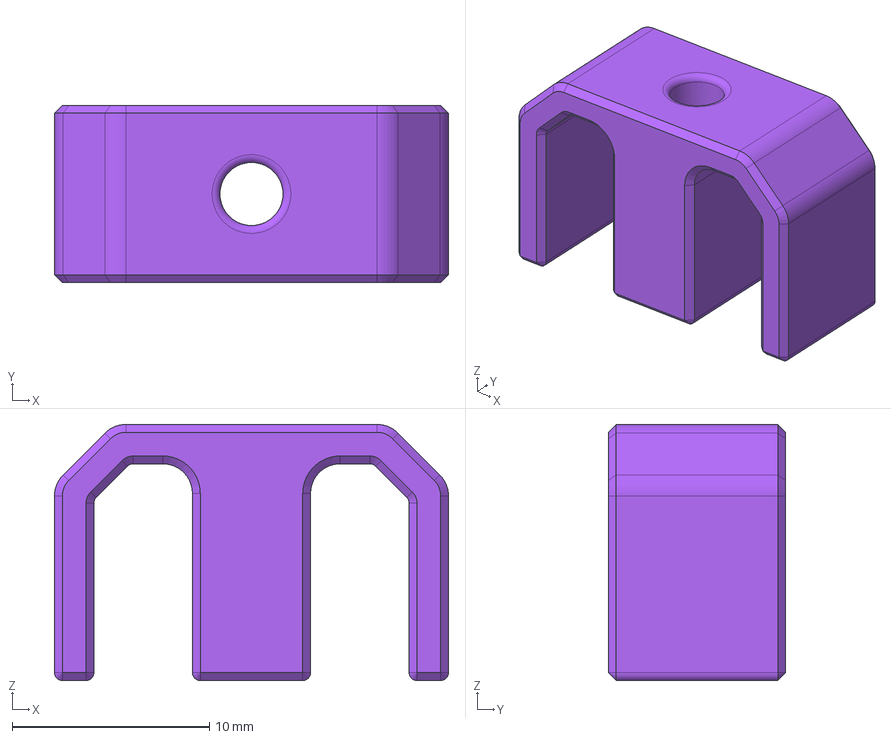
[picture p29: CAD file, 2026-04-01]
CAD/IX_Cable_management/Cable_management_clip_L.step
20.0 x 9.00 x 13.0 mm

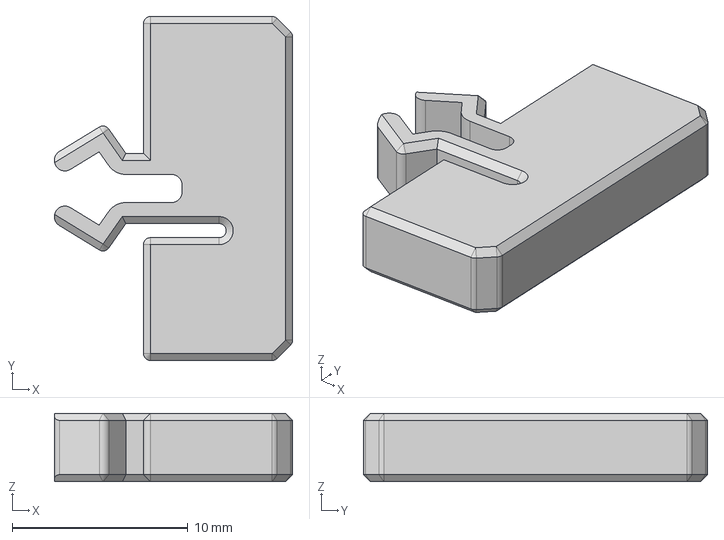
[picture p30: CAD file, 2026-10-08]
CAD/LDO_9mm_VT_NP_spacer.step
13.6 x 19.6 x 3.90 mm

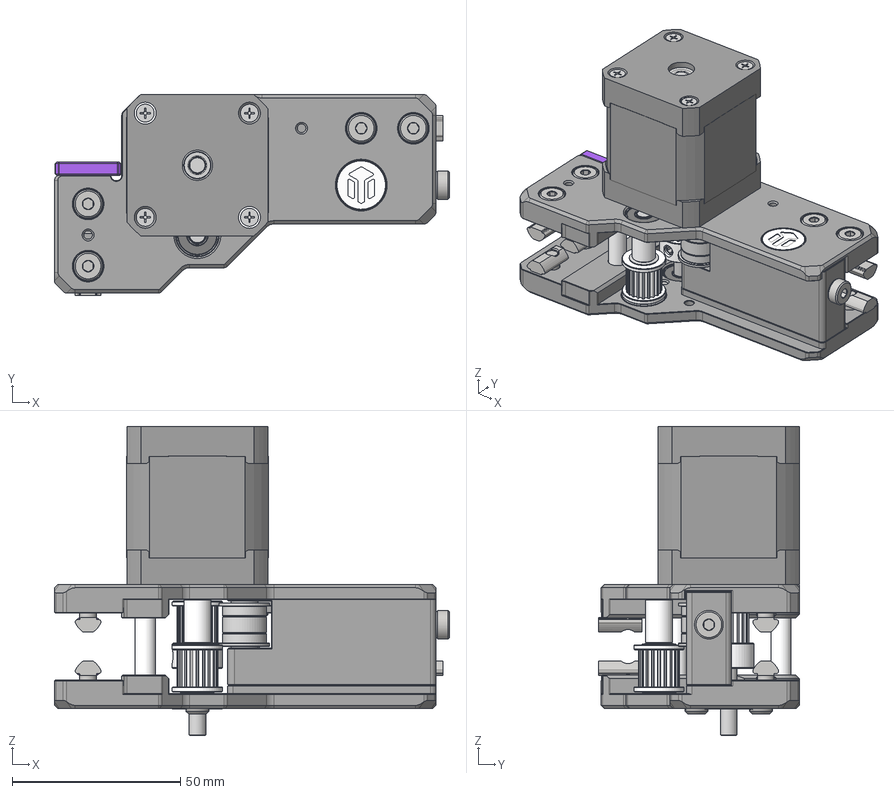
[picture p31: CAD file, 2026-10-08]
CAD/Rear_left/LDO_VT_9mm_0_NP.step
117.5 x 59.9 x 92.0 mm
VT_NP_spacer x 2
GT2 20T toothed core
Pulley flange 15x10x1.5mm x 2
LDO 5 mm shaft
GT2 20T toothed core_1
Pulley flange 15x10x1.5mm_1
Pulley removable hub 15x10x7.5mm

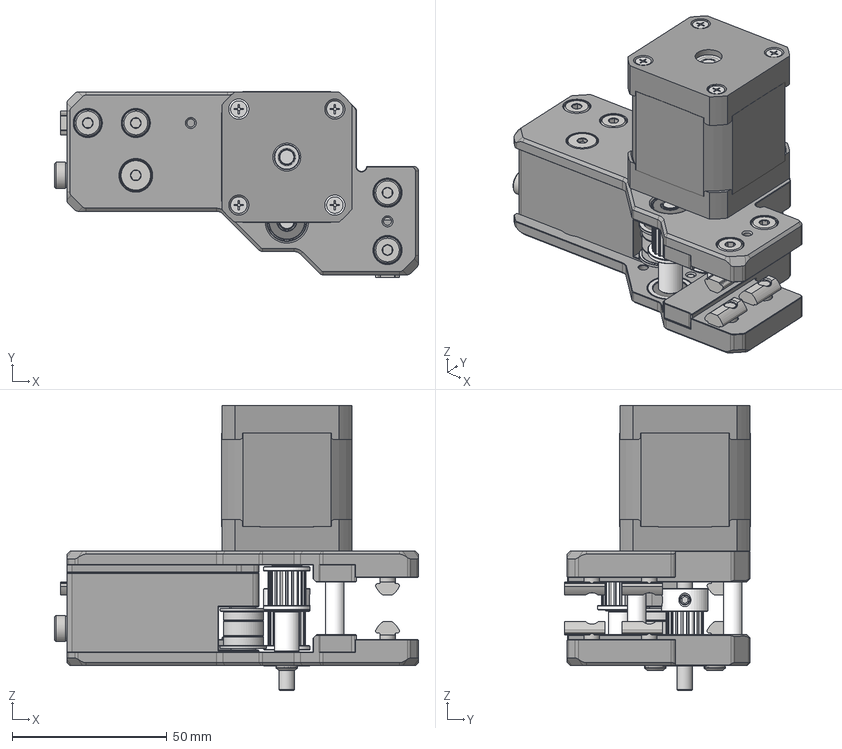
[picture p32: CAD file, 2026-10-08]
CAD/Rear_right/LDO_VT_9mm_0_FT.step
117.5 x 59.9 x 92.0 mm
GT2 20T toothed core
Pulley flange 15x10x1.5mm x 2
LDO 5 mm shaft
GT2 20T toothed core_1
Pulley flange 15x10x1.5mm_1
Pulley removable hub 15x10x7.5mm

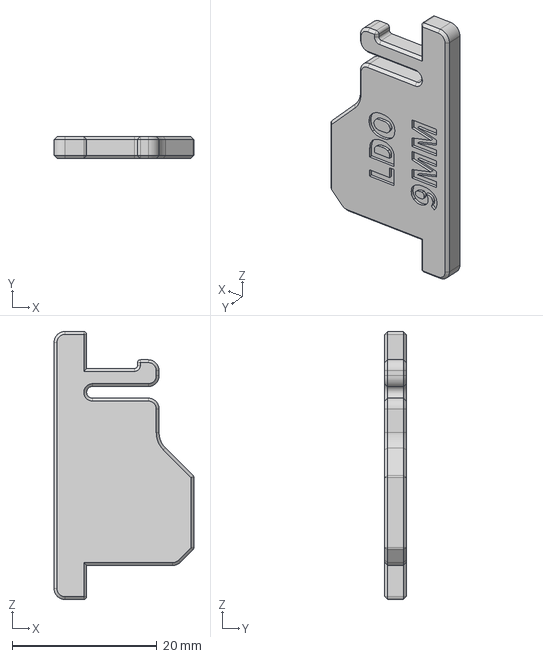
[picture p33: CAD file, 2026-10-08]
CAD/Tools/LDO_9mm_pulley_alignment_helper.step
19.3 x 3.00 x 37.0 mm

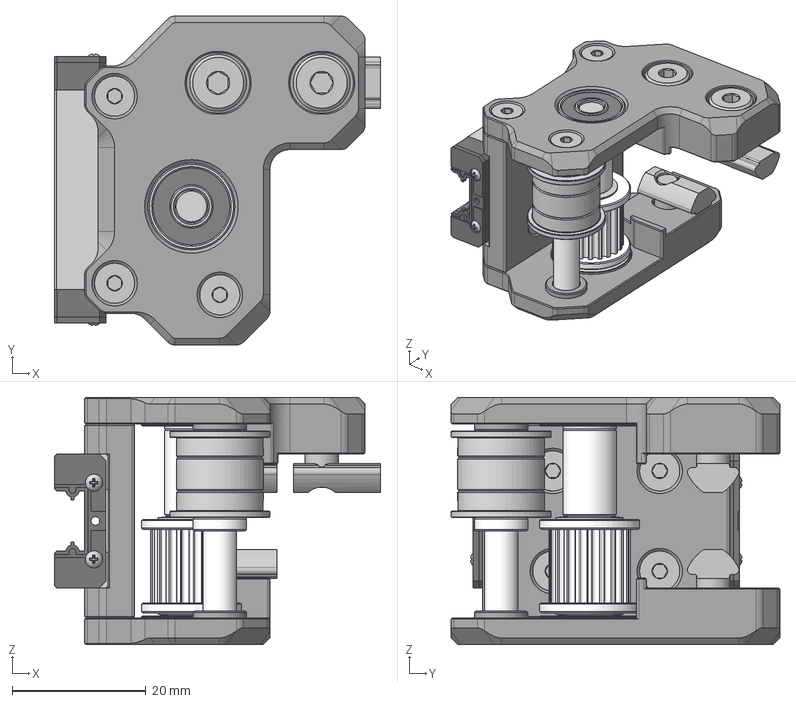
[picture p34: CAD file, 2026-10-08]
CAD/XY_left/LDO_2WD_9mm.step
48.8 x 49.2 x 37.0 mm
GT2 20T toothed core
Pulley flange 15x10x1.5mm x 2
LDO 5 mm shaft

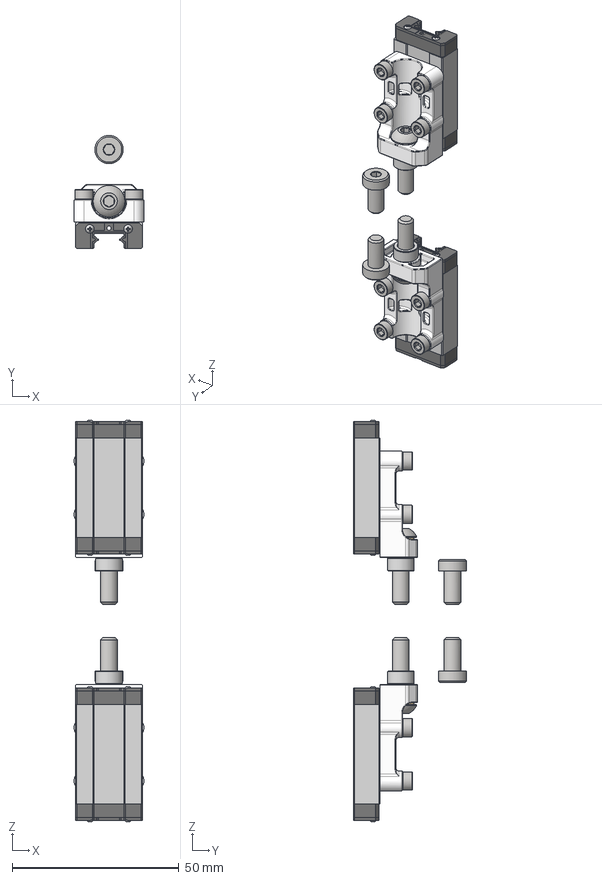
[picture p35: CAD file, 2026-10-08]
CAD/Z_joint/LDO_SLM_V2_9mm_D_FT.step
21.0 x 34.0 x 120.7 mm

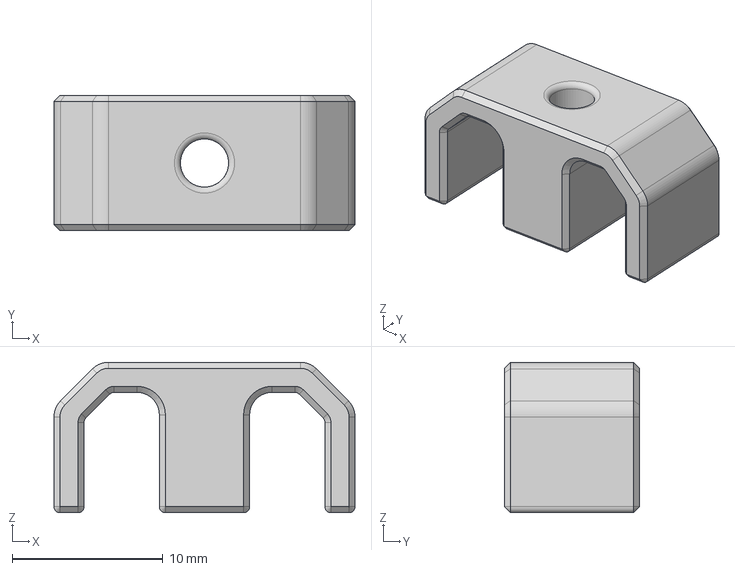
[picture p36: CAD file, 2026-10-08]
CAD/Cable_management/Cable_management_clip_M.step
20.0 x 9.00 x 10.0 mm

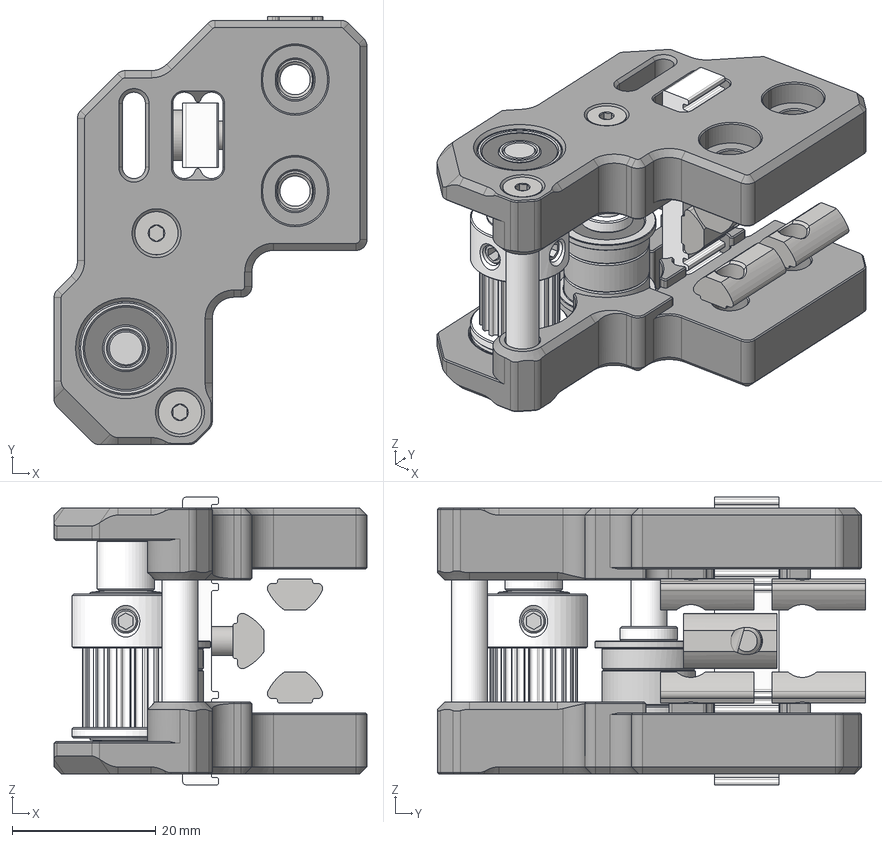
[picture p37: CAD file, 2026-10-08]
CAD/Front_right/LDO_2WD_V2_9mm.step
43.5 x 59.5 x 40.0 mm
GT2 20T toothed core
Pulley flange 15x10x1.5mm
Pulley removable hub 15x10x7.5mm

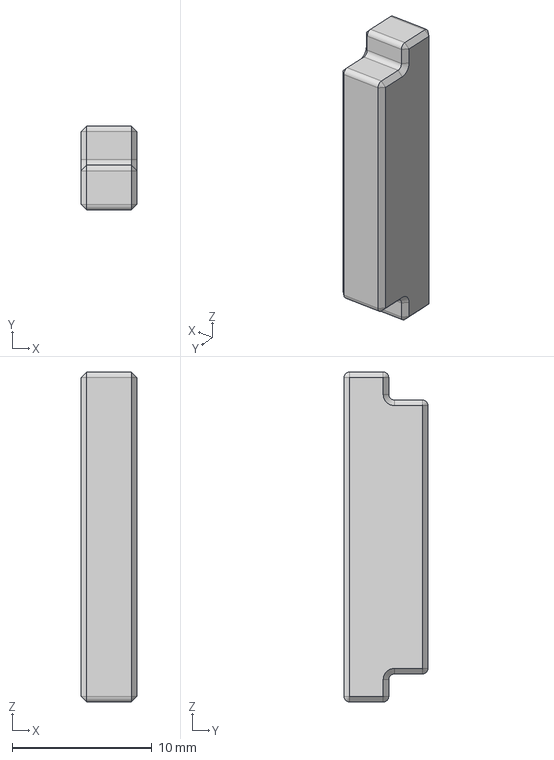
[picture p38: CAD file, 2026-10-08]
CAD/LDO_V2_FT_spacer.step
4.00 x 6.00 x 23.6 mm

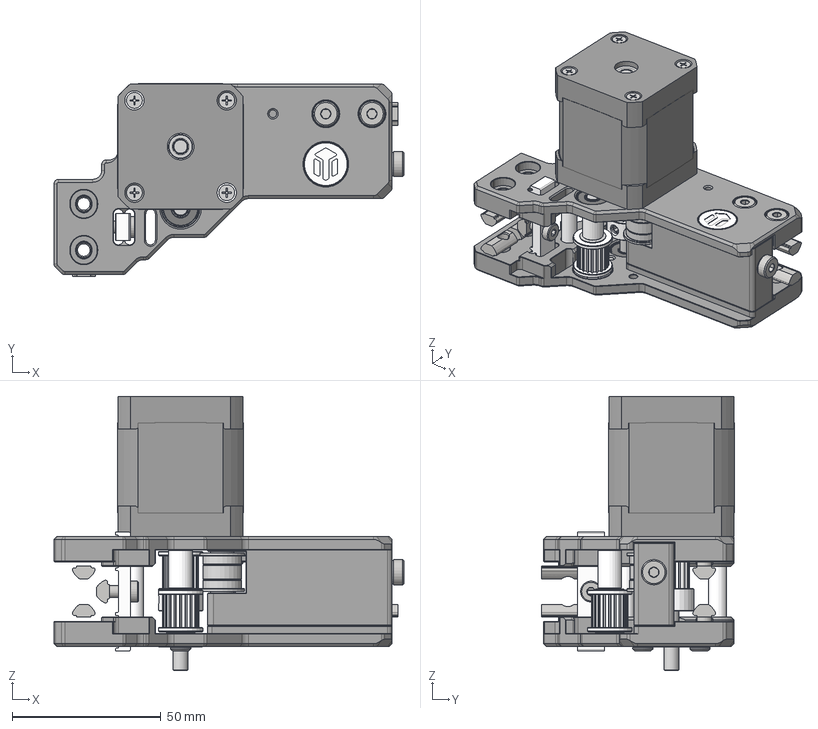
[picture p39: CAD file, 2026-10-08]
CAD/Rear_left/LDO_V2_9mm_0_NP.step
117.5 x 64.7 x 92.0 mm
GT2 20T toothed core
Pulley flange 15x10x1.5mm x 2
LDO 5 mm shaft
GT2 20T toothed core_1
Pulley flange 15x10x1.5mm_1
Pulley removable hub 15x10x7.5mm

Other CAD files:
CAD/X_Tools/LDO_9mm_pulley_alignment_helper.step
CAD/XY_right/LDO_2WD_9mm.step
CAD/Front_left/LDO_AWD_VT_9mm_0_FT.step
CAD/IX_Cable_management/Cable_management_clip_S.step
CAD/Cable_management/Cable_management_clip_L.step
CAD/Front_left/LDO_2WD_V2_9mm.step
CAD/Front_left/LDO_AWD_V2_9mm_0_FT.step
CAD/Front_left/LDO_AWD_V2_9mm_0_NP.step
CAD/Front_left/LDO_AWD_VT_9mm_0_NP.step
CAD/Front_right/LDO_2WD_VT_9mm.step
CAD/Front_right/LDO_AWD_V2_9mm_0_FT.step
CAD/Front_right/LDO_AWD_V2_9mm_0_NP.step
CAD/Front_right/LDO_AWD_VT_9mm_0_NP.step
CAD/IX_Cable_management/Cable_management_clip_M.step
CAD/Rear_left/LDO_V2_9mm_0_FT.step
CAD/Rear_left/LDO_VT_9mm_0_FT.step
CAD/Rear_right/LDO_V2_9mm_0_FT.step
CAD/Rear_right/LDO_V2_9mm_0_NP.step
CAD/Rear_right/LDO_VT_9mm_0_NP.step
CAD/XY_left/LDO_AWD_9mm.step
CAD/XY_right/LDO_AWD_9mm.step
CAD/Z_joint/LDO_Hybrid_V2_9mm_A_D_FT.step
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

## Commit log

2026-04-01 initial upload
    [Cable_management_clip_L.step, Cable_management_clip_L.stl, Cable_management_clip_M.step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]
2026-04-06 added 2WD XY-joint assembly
2026-06-01 updated repo structure
    [Cable_management_clip_L.step, Cable_management_clip_L.stl, Cable_management_clip_M.step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]
2026-10-07 Update documentation
    [Cable_management_clip_L.step, Cable_management_clip_L.stl, Cable_management_clip_M.step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]
2026-10-08 Flatten STEP structure
    [Cable_management_clip_L.step, Cable_management_clip_M.step, Cable_management_clip_S.step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]
2026-11-03 Open the Builder on the Gantry project and update the gantry kit shops
    The Builder buttons go to the Gantry project instead of the Builder's start page. The gantry kit shops add
    Stay Ready To 3D Print, follow 123-3D's new product pages and drop the search tracking from the DREMC link.
2026-11-04 Restore the gantry kit shop list
    Undoes the shop list changes of c27a187 (an added shop and two rewritten links). The list is back to
    what it was before, and only the Builder buttons keep pointing at the Gantry project.

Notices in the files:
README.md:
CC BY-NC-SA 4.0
